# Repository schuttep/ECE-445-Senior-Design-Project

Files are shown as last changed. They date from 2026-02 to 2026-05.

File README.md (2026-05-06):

# ECE 445 Senior Design Project — Networked Physical Chessboard (Group 51)

## Project Overview

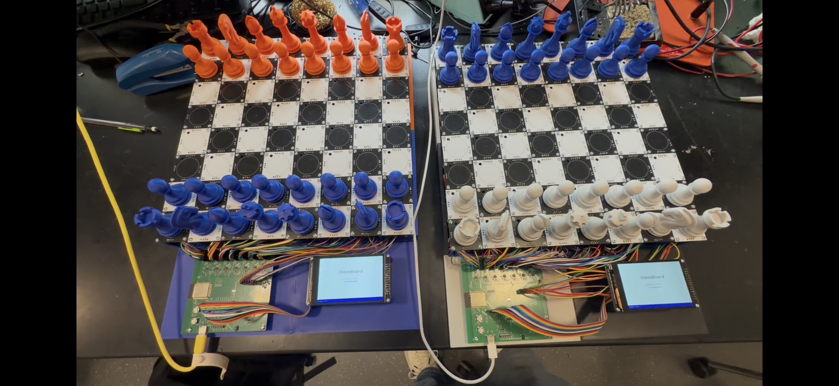
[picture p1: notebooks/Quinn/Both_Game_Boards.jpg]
Both Game Boards


This project proposes a networked physical chessboard hardware platform designed to support customizable software experiences built around real-world chess interaction. The system enables remote players to play chess using physical pieces while maintaining board synchronization through wireless communication and magnetic piece detection. This document explores the problem being solved and the approach Group 51 is taking to develop a flexible hardware foundation for future software expansion. Furthermore, the requirements and designs used to meet those requirements for each subsystem are presented. The compatibility and accuracy of the sensors and analog-to-digital converters are validated through basic calculations and engineering analysis. Finally, the ethical considerations and societal impact of the project are discussed.

---

## Table of Contents

1. [Problem Statement](#problem-statement)
2. [Proposed Solution](#proposed-solution)
3. [System Architecture](#system-architecture)
4. [Subsystem Descriptions](#subsystem-descriptions)
   - [Microcontroller & Firmware](#microcontroller--firmware)
   - [Piece Detection (Hall-Effect Sensors & ADCs)](#piece-detection-hall-effect-sensors--adcs)
   - [Display & Touchscreen UI](#display--touchscreen-ui)
   - [Wireless Communication & Backend](#wireless-communication--backend)
   - [Game Logic & FSM](#game-logic--fsm)
   - [Power & PCB Design](#power--pcb-design)
5. [Requirements & Verification](#requirements--verification)
6. [Engineering Analysis](#engineering-analysis)
7. [Ethical Considerations & Societal Impact](#ethical-considerations--societal-impact)
8. [Team Members](#team-members)
9. [Repository Structure](#repository-structure)

---

## Problem Statement

Traditional online chess is played entirely in software, disconnecting players from the tactile experience of moving physical pieces on a board. Existing products that bridge the physical and digital chess experience are either prohibitively expensive, proprietary, or locked to a single software platform. There is a need for an open, extensible hardware platform that can detect real piece positions, synchronize state between two remote boards over a network, and serve as a foundation for a rich set of software-defined game experiences.

---

## Proposed Solution

Group 51 designed and built a pair of networked physical chessboards, each built around an **ESP32-S3** microcontroller. Each board detects the position of every piece using an array of 64 Hall-effect sensors (one per square) read through eight **ADS7128** 12-bit I2C ADCs. A **480×320 IPS touchscreen** provides the primary user interface for game control, move confirmation, chat, timer display, and AI hints. The two boards communicate through an **AWS API Gateway + DynamoDB** backend, which acts as a state store to synchronize game state between remote players in real time.

| | |
|---|---|
| Assembled Board and Pieces | Full Board Assembled |

Key software features include:
- Full chess rule validation (castling, en passant, promotion, check, checkmate, stalemate) running entirely on the microcontroller.
- A finite-state machine (FSM) game controller that decouples hardware input from network and display logic.
- An on-board chat panel with a touchscreen keyboard, polled every 5 seconds.
- Optional game clocks (Rapid: 10 min/side; Bullet: 5 min/side) tracked on the Arduino.
- Stockfish AI hints (3 per game) fetched from the cloud backend.
- A WiFi network selector and password entry screen rendered at runtime.

---

## System Architecture

```
┌──────────────────────────────────────────────────────────┐
│                     ESP32-S3 (per board)                 │
│                                                          │
│  ┌────────────┐   ┌──────────────┐   ┌────────────────┐ │
│  │  ADC Layer │   │  Game Logic  │   │  Display Layer │ │
│  │ 8× ADS7128 │──▶│  (FSM + rule │──▶│ ST7365P 480×320│ │
│  │ 64 Hall Sx │   │  validation) │   │ GT911 touch    │ │
│  └────────────┘   └──────┬───────┘   └────────────────┘ │
│                          │                               │
│                   ┌──────▼───────┐                       │
│                   │  WiFi / HTTPS│                       │
│                   │  api_connect │                       │
│                   └──────┬───────┘                       │
└──────────────────────────┼───────────────────────────────┘
                           │ HTTPS / AWS API Gateway
              ┌────────────▼────────────────┐
              │  AWS Lambda + DynamoDB       │
              │  (game state, move history,  │
              │   chat, timer, AI hints)     │
              └─────────────────────────────┘
                           │
┌──────────────────────────┼───────────────────────────────┐
│                     ESP32-S3 (remote board)               │
│                        (mirror architecture)              │
└──────────────────────────────────────────────────────────┘
```

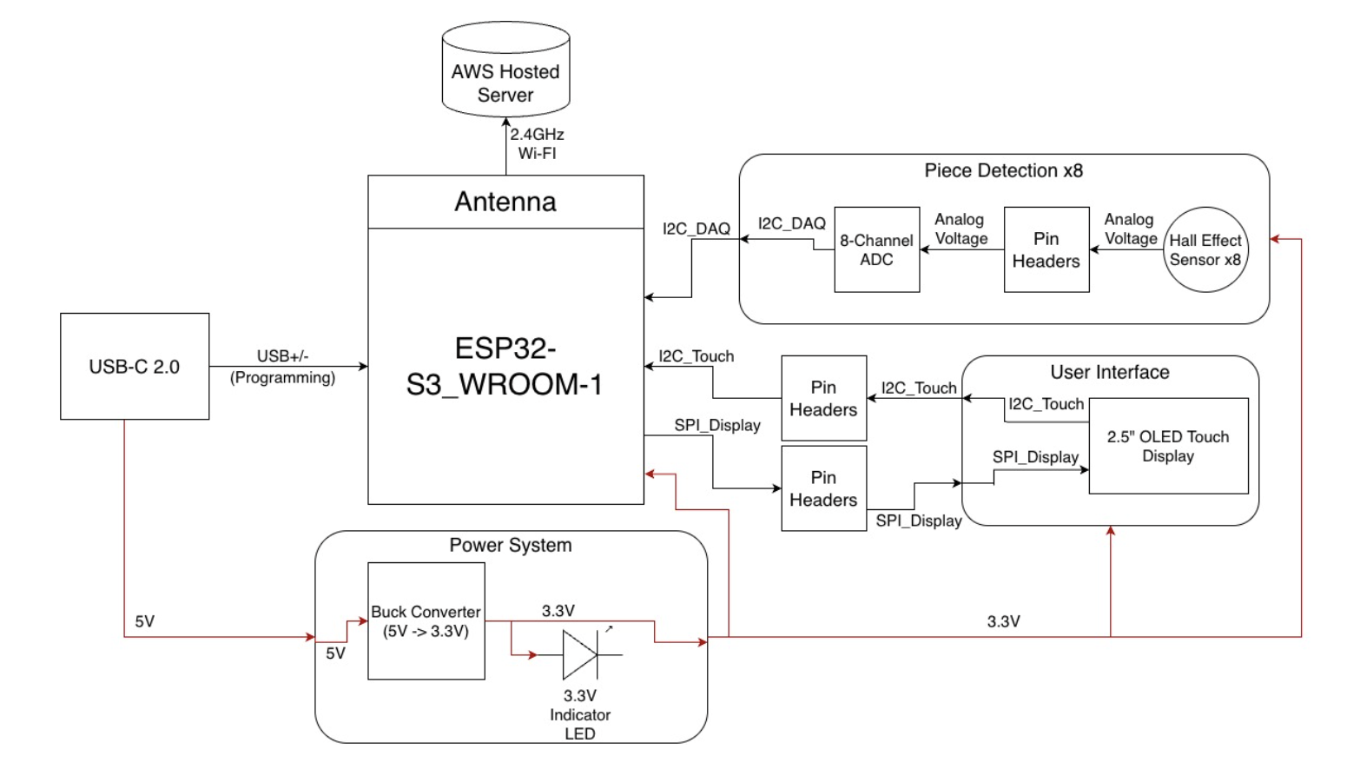
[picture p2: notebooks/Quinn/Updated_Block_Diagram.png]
System Block Diagram


---

## Subsystem Descriptions

### Microcontroller & Firmware

**Part:** Espressif ESP32-S3  
**Interfaces:** SPI (display), I2C × 2 (touch + ADCs), WiFi 802.11 b/g/n

The ESP32-S3 was selected for its dual-core Xtensa LX7 processor, ample GPIO, hardware SPI/I2C peripherals, and built-in WiFi. Two independent I2C buses are used: `Wire` for the touchscreen controller and `Wire1` (GPIO 38/39, 100 kHz) for the eight ADC chips. The main loop runs a tight read → FSM-tick → redraw cycle; only dirty screen regions are repainted each iteration to maintain UI responsiveness.

**Firmware modules:**

| File | Responsibility |
|---|---|
| `ChessBoard.ino` | Hardware init, UI state machine, touch dispatch, main loop |
| `gameloop.cpp/.h` | FSM game controller (12 states) |
| `gamelogic.cpp/.h` | Pure chess rule validation |
| `ADC_driver.cpp/.h` | ADS7128 driver, board FEN assembly |
| `display_driver.cpp/.h` | All screen rendering with dirty-cell cache |
| `api_connect.cpp/.h` | HTTPS communication with AWS backend |
| `wifi_manager.cpp/.h` | WiFi scan and credential management |

---

### Piece Detection (Hall-Effect Sensors & ADCs)

**Sensors:** 64 Hall-effect sensors, one per square (magnetic piece bases)  
**ADCs:** 8× Texas Instruments ADS7128 (12-bit, 8-channel, I2C)  
**I2C Addresses:** `0x10` – `0x17`

Each chess piece has a small permanent magnet embedded in its base. The Hall-effect sensor beneath each square measures the magnetic field strength and polarity. The ADS7128 converts the analog sensor voltage to a 12-bit digital value. The firmware interprets deviations from the 2048 mid-scale baseline:

| Condition | ADC Value | Interpretation |
|---|---|---|
| No piece | ~2048 | Empty square (`.`) |
| N-pole detected (positive deviation ≥ 300 counts) | > 2348 | White piece (`P`) |
| S-pole detected (negative deviation ≥ 300 counts) | < 1748 | Black piece (`p`) |

The physical column-to-chip mapping compensates for PCB routing constraints:

```
File a → h  maps to chips:  {7, 6, 5, 4, 0, 1, 2, 3}
```

The `localIsWhite` flag mirrors the entire board reading when the local player is Black, ensuring rank 8 always corresponds to the opponent's back rank regardless of board orientation.

**ADC Self-Test:** `testADCs()` probes all eight chips and all 64 channels at startup, reporting any unresponsive sensors.

| Game Piece with Magnet | Magnet Installation | Hall-Effect Sensor Prototype | ADC Testing Setup |
|---|---|---|---|
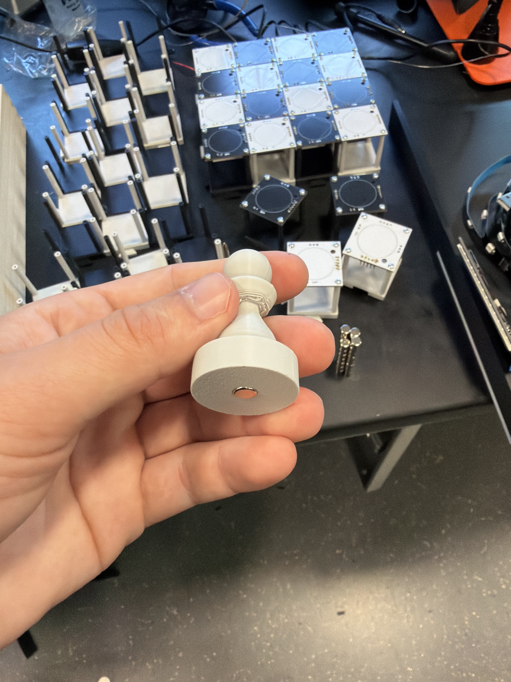
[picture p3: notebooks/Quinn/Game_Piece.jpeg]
Game Piece
|  | Magnets in Pieces | Hall Effect Sensors on Breadboard | ADC Testing Setup |

---

### Display & Touchscreen UI

**Display:** DFRobot ST7365P 480×320 IPS, Hardware SPI  
**Touchscreen:** Goodix GT911 capacitive, I2C (`Wire`, address `0x5D`)

The display operates in landscape mode (480×320). Raw portrait touch coordinates from the GT911 are transformed to landscape at runtime:

$$t_x = 479 - \text{raw}_y, \quad t_y = \text{raw}_x$$

A per-square dirty-cache system (`s_dirtyCells`, 64-bit bitfield) ensures only changed squares are redrawn each loop iteration, keeping frame latency low even on a 480×320 panel.

**UI Screens:**

| Screen State | Description |
|---|---|
| `MENU` | Main menu: Create Game, Join Game, Board Test |
| `GAME` | Live board + right panel (clocks, chat, hint button) |
| `BOARD_SYNC` | Overlay highlighting missing or extra pieces during setup |
| `WIFI_LIST` | Scanned network list with signal strength |
| `WIFI_PASS_SCREEN` | On-screen keyboard for WiFi password entry |
| `TIMER_MODE_SELECT` | Select Unlimited / Rapid / Bullet time control |
| `AI_MODE_SELECT` | Select Easy / Medium / Hard Stockfish difficulty |
| `BOARD_TEST` | Raw sensor value display for hardware validation |

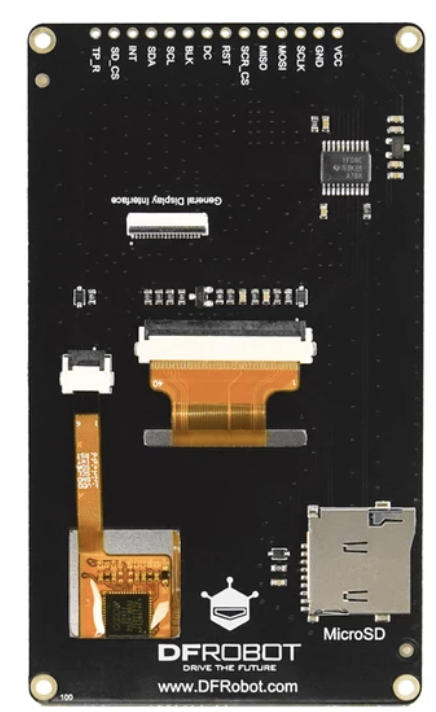
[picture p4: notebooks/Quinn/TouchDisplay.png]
Touch Display UI


---

### Wireless Communication & Backend

**Protocol:** HTTPS (TLS) over WiFi 802.11 b/g/n  
**Backend:** AWS API Gateway → AWS Lambda → DynamoDB  
**Base URL:** `https://j3zvk9adv0.execute-api.us-east-2.amazonaws.com/api/v1`

The backend is a **stateless REST API**; chess rule enforcement and move validation run entirely on the ESP32-S3. The server stores game state, move history, timer state, and chat messages. Optimistic concurrency control (`expectedVersion`) prevents conflicting simultaneous updates.

**API Endpoints:**

| Method | Endpoint | Function |
|---|---|---|
| `GET` | `/games/1` | Fetch current game state (FEN, turn, version) |
| `GET` | `/games/1/moves` | Fetch full move history |
| `POST` | `/games/1/moves` | Submit a validated move + updated FEN |
| `POST` | `/games/1/reset` | Reset game to starting position |
| `POST` | `/games/1/heartbeat` | Connectivity keepalive (every ~3 s) |
| `POST` | `/games/1/timeout` | Notify server of clock expiry |
| `GET` | `/games/1/messages` | Fetch chat messages |
| `POST` | `/games/1/messages` | Send a chat message |
| `POST` | `/games/1/hint` | Request Stockfish best-move hint |

The Amazon Root CA 1 TLS certificate is embedded directly in firmware (valid until 2038). All API calls verify WiFi connectivity before attempting a request.

---

### Game Logic & FSM

**FSM Controller (`gameloop.cpp`)** drives the full game lifecycle through 12 states:

| State | Description |
|---|---|
| `CGM_WAIT_FOR_GAME_START` | Idle on the menu |
| `CGM_JOIN_POLLING` | Polling server until opponent's first move appears |
| `CGM_GAME_INITIALIZATION` | Fetching initial game state from server |
| `CGM_BOARD_SYNC` | Waiting for physical board to match the expected position |
| `CGM_LOCAL_TURN_WAIT_FOR_BOARD` | Waiting for player to lift and place a piece |
| `CGM_LOCAL_TURN_PROMOTION` | Waiting for promotion piece selection via touchscreen |
| `CGM_LOCAL_TURN_VALIDATE` | Validating the detected move against chess rules |
| `CGM_LOCAL_TURN_CONFIRM` | Waiting for player to confirm or cancel the move |
| `CGM_SEND_STATE` | Sending confirmed move and FEN to server |
| `CGM_WAIT_FOR_REMOTE_MOVE` | Polling server for opponent's move |
| `CGM_APPLY_REMOTE_MOVE` | Waiting for player to replicate opponent's move on the board |
| `CGM_GAME_END` | Game over (checkmate, stalemate, timeout) |

**Rule Validator (`gamelogic.cpp`)** is a self-contained chess engine with no hardware or network dependencies. It validates any before/after FEN pair against the complete ruleset including castling rights, en passant captures, pawn promotion, and king safety (check, checkmate, stalemate detection).

| Working Single Board Game | Mock Demo |
|---|---|
| Working Single Board Game | Mock Demo |

---

### Power & PCB Design

The project uses two custom PCBs:

**Main Board PCB** (`ECE-445-PCBs/Main_Board/`)  
Hosts the ESP32-S3, display/touch connectors, power regulation, and I2C bus breakout for the ADC array. Gerber files are provided for fabrication.

**Tile PCB** (`ECE-445-PCBs/Tile_PCB/`)  
A small per-square PCB carrying one Hall-effect sensor. 64 tiles tile together to form the 8×8 sensing matrix. Each tile connects to the column ADC via a shared I2C bus segment.

**Main Board PCB:**

| 3D View | PCB Routing | Assembled & Soldered |
|---|---|---|
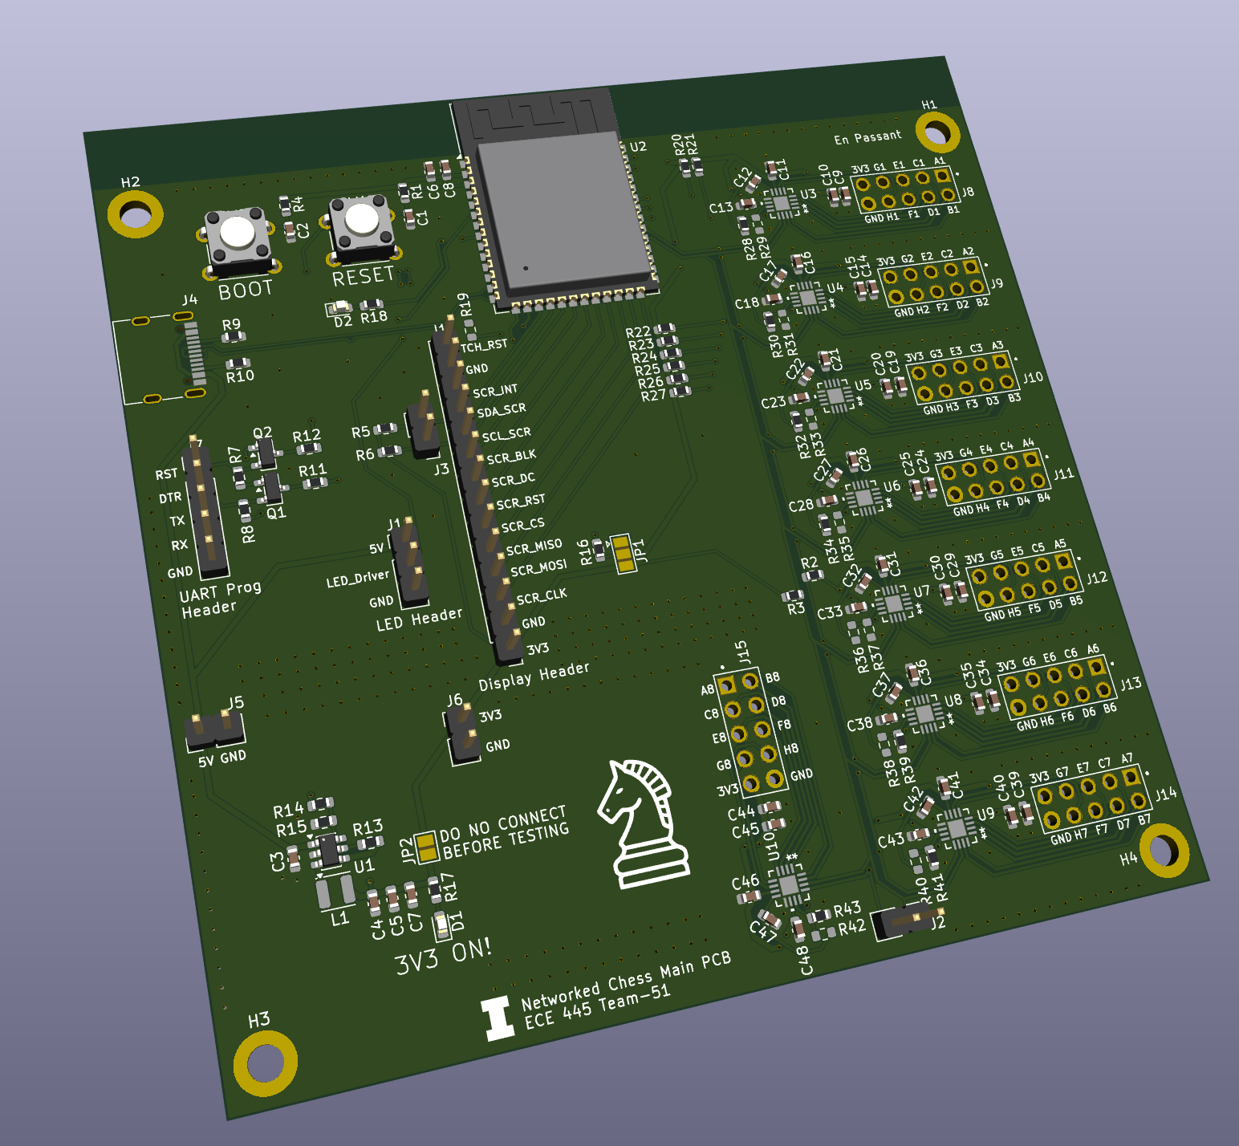
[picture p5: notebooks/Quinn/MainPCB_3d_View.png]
Main PCB 3D View
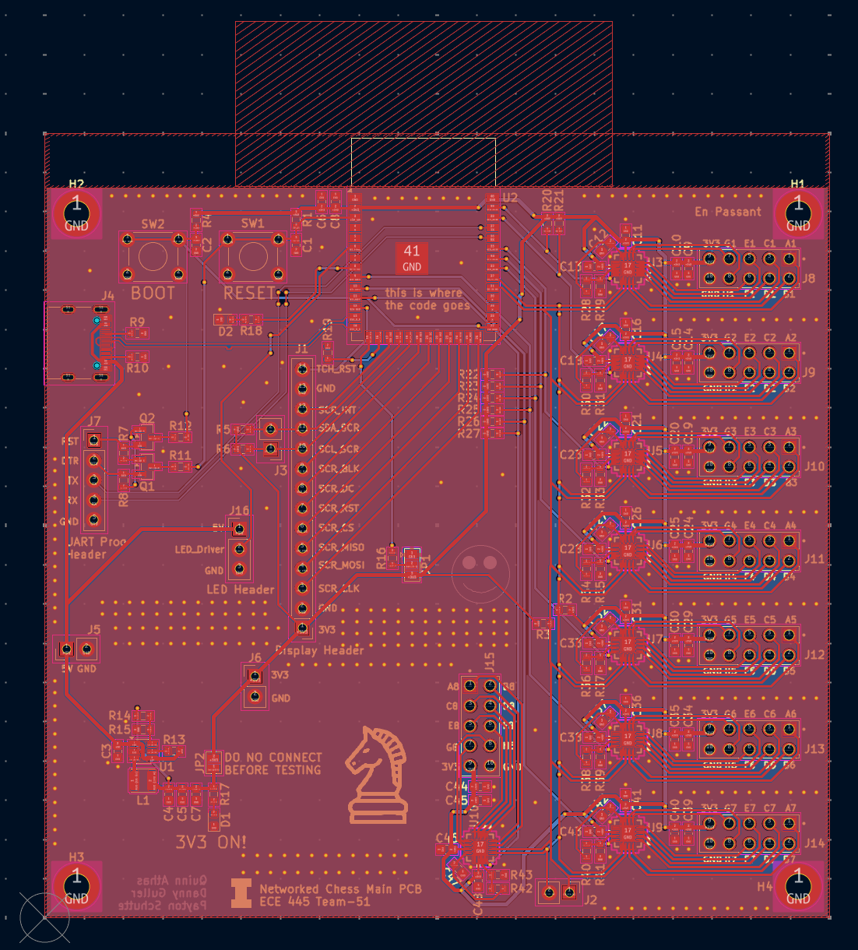
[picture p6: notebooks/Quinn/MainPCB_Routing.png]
Main PCB Routing
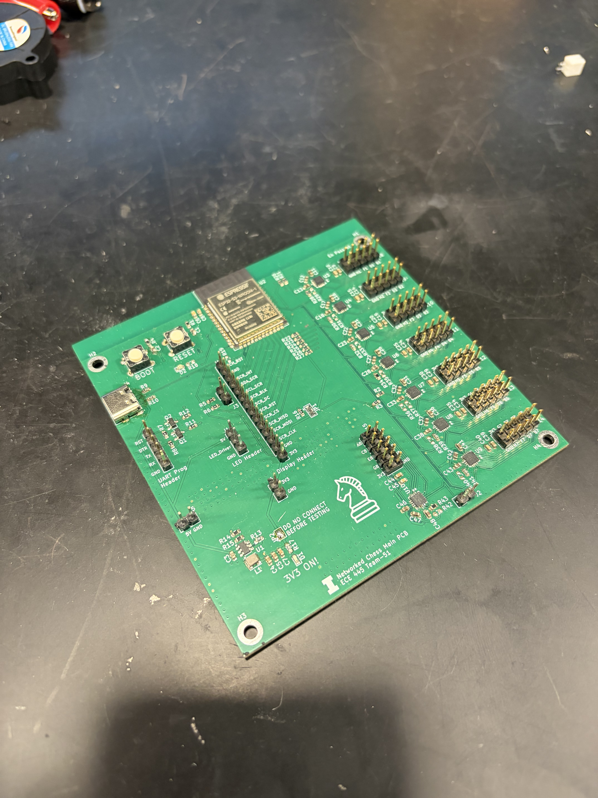
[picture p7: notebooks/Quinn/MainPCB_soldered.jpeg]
Main PCB Soldered
|  |  |  |

**Tile PCB:**

| 3D View (Front) | 3D View (Back) | PCB Routing | Soldered | Wiring |
|---|---|---|---|---|
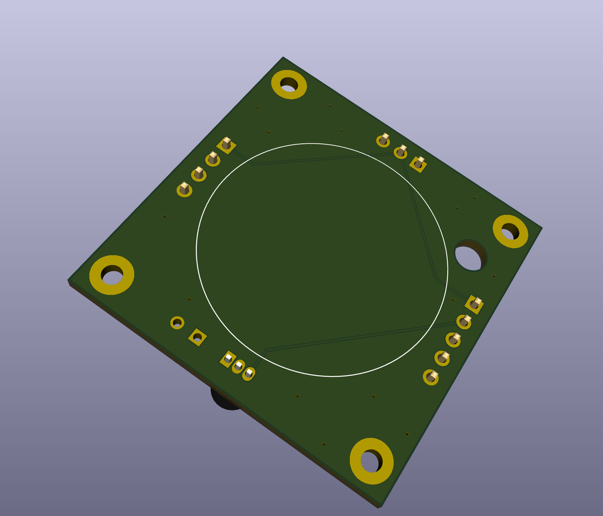
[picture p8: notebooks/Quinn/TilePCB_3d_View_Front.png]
Tile PCB 3D Front
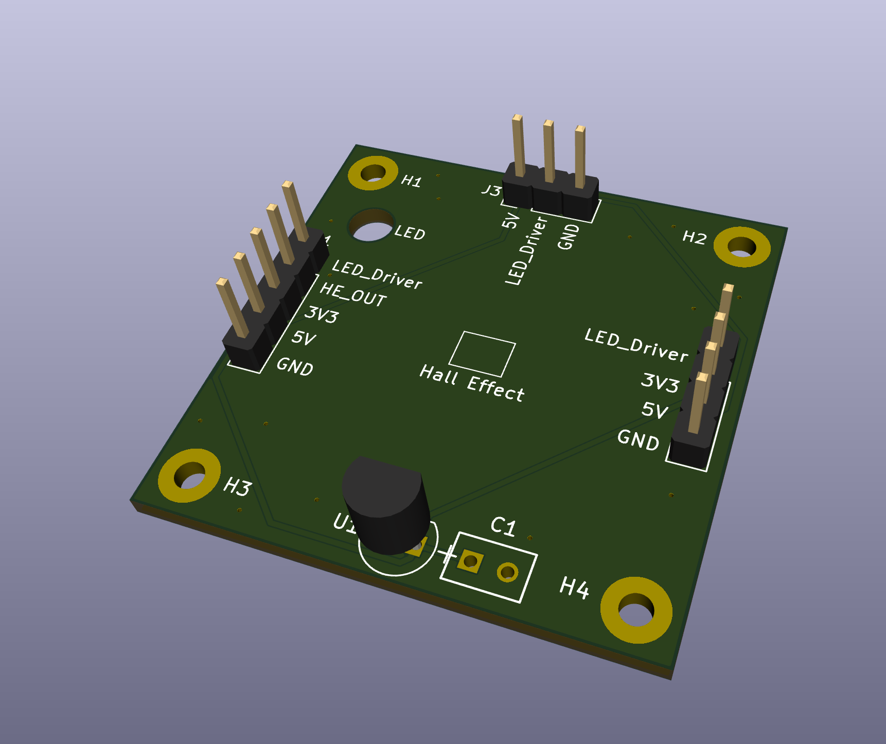
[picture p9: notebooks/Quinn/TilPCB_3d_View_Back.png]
Tile PCB 3D Back
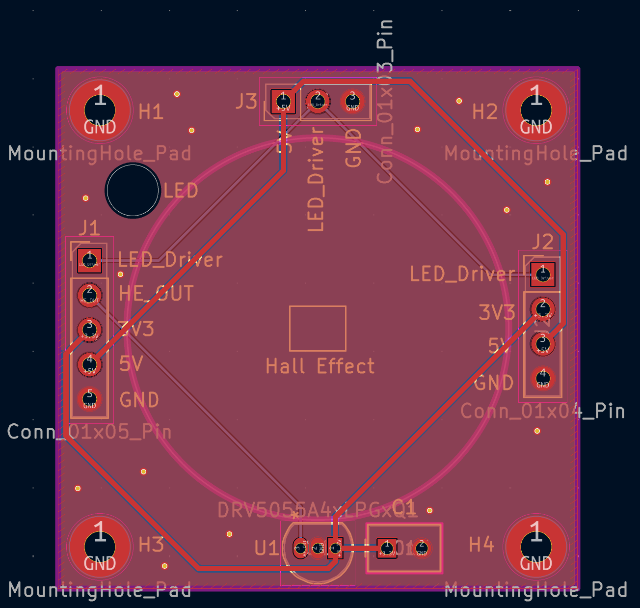
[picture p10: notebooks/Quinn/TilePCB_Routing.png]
Tile PCB Routing
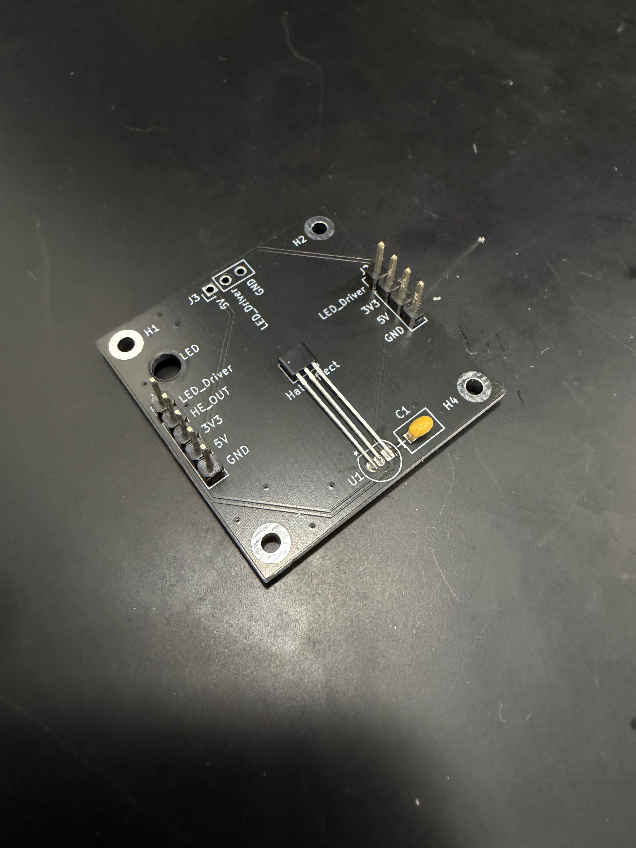
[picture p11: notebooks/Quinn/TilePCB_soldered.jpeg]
Tile PCB Soldered
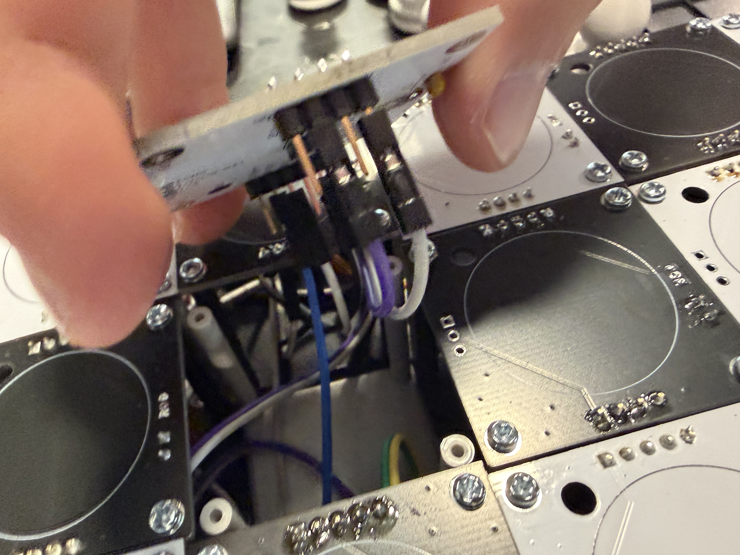
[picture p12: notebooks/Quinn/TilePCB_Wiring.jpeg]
Tile PCB Wiring
|  |  |  |  |  |

**3D-Printed Enclosure** (Fusion 360 source files and STLs in `Enclosure/`):

| Baseplate Corner | Baseplate Edge | Display Support | Tile PCB Support | Main Board Support |
|---|---|---|---|---|
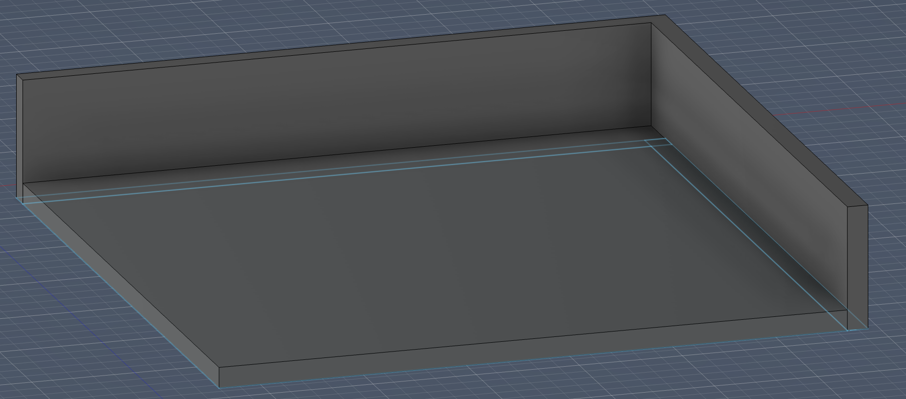
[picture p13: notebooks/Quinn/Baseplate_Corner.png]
Baseplate Corner
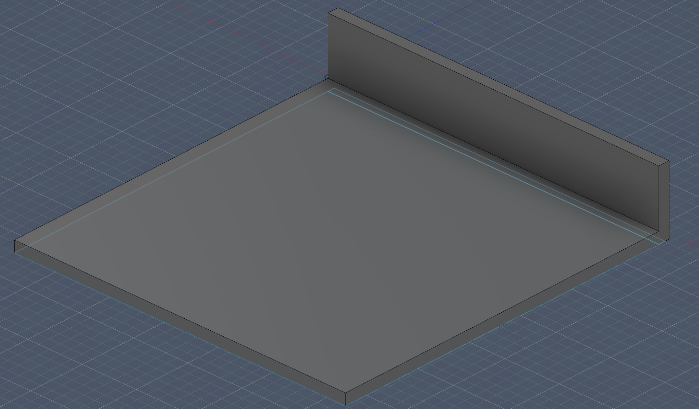
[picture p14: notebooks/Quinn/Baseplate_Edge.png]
Baseplate Edge
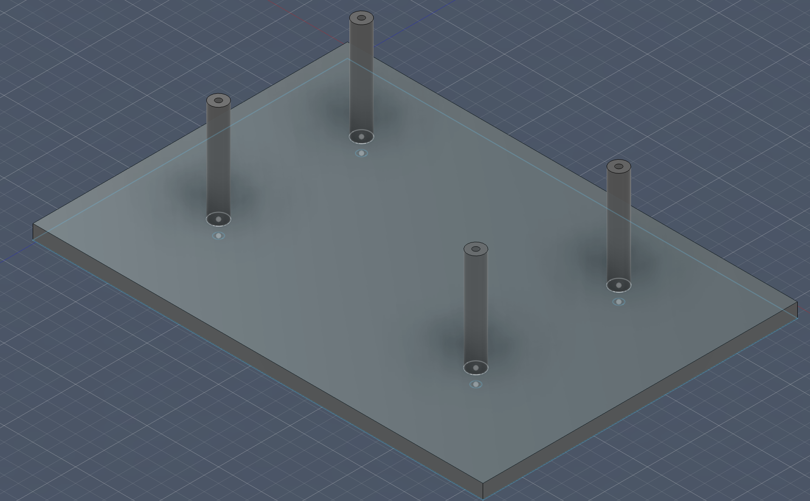
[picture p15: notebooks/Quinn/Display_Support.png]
Display Support
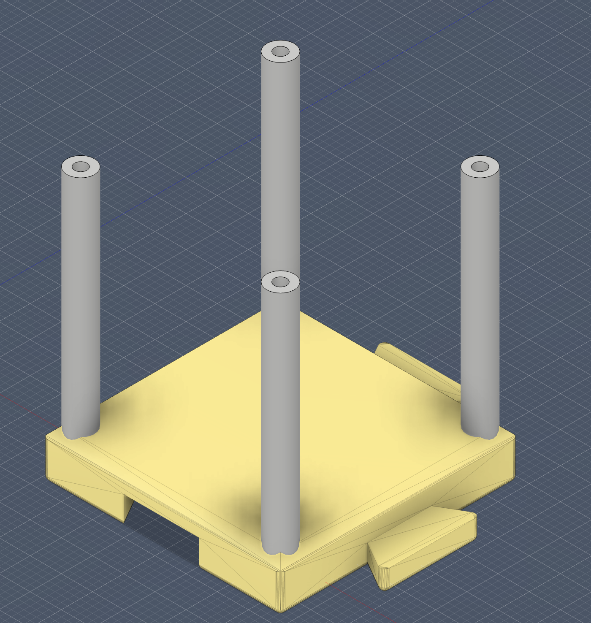
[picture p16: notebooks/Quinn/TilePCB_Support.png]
Tile PCB Support
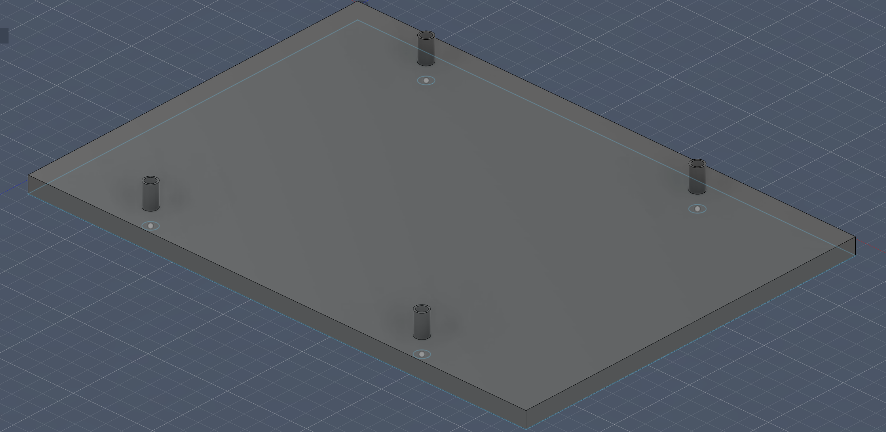
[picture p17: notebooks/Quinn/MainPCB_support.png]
Main Board Support
|  |  |  |  |  |

---

## Build Process

| Reflow Soldering Main PCB | Soldering Tile PCBs | Quarter Board Assembled | Full Board Assembled |
|---|---|---|---|
| Reflow Soldering Main PCB | Soldering Tile PCBs | Quarter of Board Assembled | Full Board Assembled |

| First Completed Board | Second Completed Board |
|---|---|
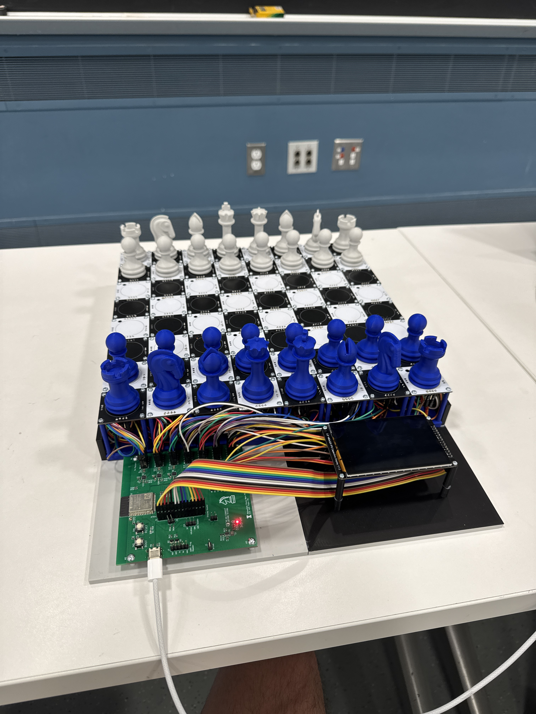
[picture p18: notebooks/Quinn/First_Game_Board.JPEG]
First Game Board
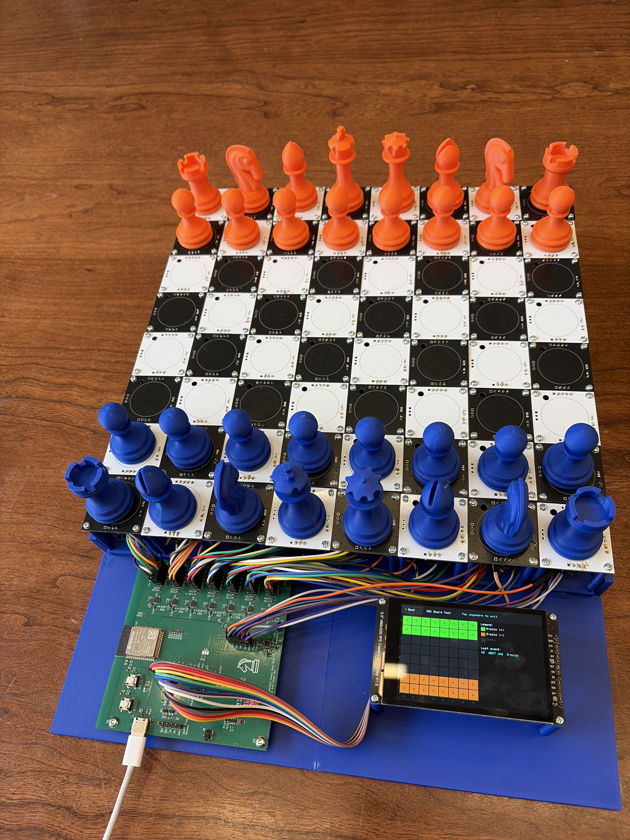
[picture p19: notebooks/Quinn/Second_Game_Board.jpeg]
Second Game Board
|  |  |

---

## Requirements & Verification

| Requirement | Verification Method |
|---|---|
| All 64 squares reliably detect piece presence/absence | ADC self-test (`testADCs()`); manual placement of pieces across all squares |
| Board FEN matches physical position within 1 loop cycle (~50 ms) | Serial monitor comparison of sensor FEN vs. expected FEN during test positions |
| WiFi connection established within 10 seconds of credential entry | Timed connection attempts in `wifi_manager.cpp` |
| Move validated and sent to server within 3 seconds of confirmation | Timestamped serial log during live game |
| Remote move received and displayed within 5 seconds of opponent submission | End-to-end latency test between two boards |
| Chat messages delivered within 10 seconds | Measured poll cycle (`MSG_POLL_INTERVAL_MS = 5000 ms`) |
| Timer accuracy within ±1 second per 10 minutes of play | Comparison of Arduino millis() clock against reference timer |
| Touchscreen registers all button presses with < 100 ms response | Manual interaction testing across all UI screens |

---

## Engineering Analysis

### Hall-Effect Sensor Threshold Calculation

The ADS7128 is a 12-bit ADC with a 3.3 V reference, giving a resolution of:

$$\Delta V = \frac{3.3\text{ V}}{2^{12}} \approx 0.806 \text{ mV/count}$$

The firmware uses a ±300 count threshold around the 2048 midpoint:

$$\Delta V_{\text{threshold}} = 300 \times 0.806 \text{ mV} \approx 242 \text{ mV}$$

This threshold was chosen to be large enough to reject sensor noise (empirically measured at < 20 counts RMS) while reliably detecting the magnetic field of the embedded piece magnets (measured at 400–800 counts deviation at rated piece height).

### I2C Bus Timing

Eight ADS7128 chips share the `Wire1` bus at 100 kHz. A full board scan reads 64 channels sequentially. Each channel read requires approximately 3 I2C transactions (register select + 2-byte read), each taking:

$$t_{\text{transaction}} \approx \frac{3 \times 18 \text{ bits}}{100{,}000 \text{ bps}} \approx 540 \text{ µs}$$

Total scan time estimate:

$$t_{\text{scan}} \approx 64 \times 540 \text{ µs} \approx 34.6 \text{ ms}$$

This is well within the target loop period of ~50 ms, leaving sufficient headroom for display updates, FSM logic, and WiFi polling.

### Optimistic Concurrency

The server uses a version counter to prevent conflicting move submissions. If both boards somehow attempt to push a move simultaneously, the server rejects the request with a lower `expectedVersion`, and the losing board re-fetches the current state before retrying. This eliminates the need for server-side locking in a two-player scenario.

---

## Ethical Considerations & Societal Impact

**Accessibility:** The physical-digital bridge this project creates enables players who prefer or require tactile interaction — including visually impaired users with adapted piece markings — to participate in networked chess. The touchscreen UI is designed with large tap targets and high-contrast color themes.

**Privacy & Data:** The system transmits only game state (FEN strings), optional chat messages, and anonymous heartbeat signals. No personally identifiable information is collected or stored by the backend. Credentials (WiFi SSID/password) are stored locally in `secrets.h` and are never transmitted to the cloud.

**Security:** All client–server communication is over TLS (HTTPS) with a pinned Amazon Root CA certificate. The backend uses optimistic concurrency control to prevent unauthorized state manipulation. WiFi credentials are excluded from version control via `.gitignore`.

**Open Hardware Philosophy:** All PCB design files (KiCad), 3D enclosure models (Fusion 360), and firmware are maintained in this repository, enabling the community to reproduce, modify, and extend the platform without proprietary lock-in.

**Societal Impact:** Chess is a globally played game with deep cultural significance. By lowering the cost and technical barrier to networked physical chess, this platform has the potential to reconnect distributed families and communities through shared physical play experiences, and to serve as an educational platform for embedded systems and game AI coursework.

---

*ECE 445 — Senior Design Laboratory, University of Illinois Urbana-Champaign*  
*Group 51 — Spring 2026*

---

## Repository Structure

```
ChessBoard/          ← Production firmware (ESP32-S3 Arduino sketch)
ECE-445-PCBs/        ← KiCad PCB design files + Gerbers
Enclosure/           ← Fusion 360 source files + STLs
prototypes/          ← Early-stage / exploratory sketches (non-production)
backend/
  api.py               ← AWS Lambda handler (backend)
  api.md               ← Full REST API endpoint reference
docs/
  diagrams/
    ChessBoard.drawio  ← System block diagram (editable)
Danny/               ← Build photos and design notes
Quinn/               ← Build photos, PCB renders, enclosure renders
Payton/              ← Design notes
README.md            ← This file
```

**Prototype sketches** (`prototypes/`) are independent `.ino` files used during development to validate individual subsystems (ADC driver, display, hall sensor, WiFi). They are not part of the production build in `ChessBoard/`.

**API documentation** is maintained in [`backend/api.md`](backend/api.md). The backend source is [`backend/api.py`](backend/api.py) (AWS Lambda + DynamoDB).

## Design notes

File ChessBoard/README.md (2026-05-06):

# ChessBoard — ECE 445 Senior Design Project

A networked, physical chess board built on the ESP32-S3. Two boards communicate through an AWS backend, allowing two players to play chess on real hardware with piece detection, touchscreen UI, a live chat panel, optional chess clocks, and Stockfish AI hints.

---

## Table of Contents

1. [Hardware Overview](#hardware-overview)
2. [Pin Assignments](#pin-assignments)
3. [Dependencies / Libraries](#dependencies--libraries)
4. [Project Setup](#project-setup)
5. [File Reference](#file-reference)
6. [Backend API](#backend-api)
7. [Game Flow](#game-flow)
8. [Testing Utilities](#testing-utilities)

---

## Hardware Overview

| Component | Part | Interface |
|---|---|---|
| Microcontroller | ESP32-S3 | — |
| Display | DFRobot ST7365P 480×320 IPS | Hardware SPI |
| Touchscreen | GT911 capacitive | I2C (`Wire`, 0x5D) |
| Hall-effect ADCs | 8× ADS7128 (addresses 0x10–0x17) | I2C (`Wire1`, 100 kHz) |
| Hall sensors | 64× (one per square) | Analog via ADS7128 |

Each ADS7128 chip handles one column of the board (8 squares = 8 channels). Chips are physically wired out of order; the mapping is handled in firmware — see `ADC_driver.cpp`.

The display is in **landscape** mode (480×320). The touchscreen reports raw portrait coordinates which are converted to landscape in `ChessBoard.ino`:
```
tx = 479 - raw_y
ty = raw_x
```

---

## Pin Assignments

Defined in `headers.h`:

| Pin | GPIO | Function |
|---|---|---|
| `SDA_DAQ` | 38 | ADC I2C data (Wire1) |
| `SCL_DAQ` | 39 | ADC I2C clock (Wire1) |
| `SCR_SCLK` | 45 | Display SPI clock |
| `SCR_MOSI` | 48 | Display SPI data |
| `SCR_MISO` | 47 | Display SPI (unused) |
| `SCR_CS` | 21 | Display chip select |
| `SCR_RST` | 14 | Display reset |
| `SCR_DC` | 13 | Display data/command |
| `SCR_BLK` | 12 | Display backlight |
| `SCR_I2C_SCL` | 11 | Touch I2C clock (Wire) |
| `SCR_I2C_SDA` | 10 | Touch I2C data (Wire) |
| `SCR_INT` | 9 | Touch interrupt |
| `SCR_TCH_RST` | 8 | Touch reset |

---

## Dependencies / Libraries

Install all libraries through the Arduino IDE Library Manager or manually place them in your Arduino `libraries/` folder.

| Library | Purpose |
|---|---|
| `DFRobot_GDL` | ST7365P display driver |
| `DFRobot_Touch` | GT911 touchscreen driver |
| `WiFi` | Built-in ESP32 WiFi |
| `WiFiClientSecure` | TLS/HTTPS connections |
| `HTTPClient` | HTTP requests to AWS |
| `ArduinoJson` | JSON parsing/serialization |
| `Wire` | I2C (built-in) |
| `SPI` | SPI (built-in) |

**Board**: Install **esp32 by Espressif Systems** via the Arduino Boards Manager. Select **ESP32S3 Dev Module** as the target board.

---

## Project Setup

### 1. Clone / copy the sketch

The Arduino IDE requires the sketch folder name to match the `.ino` filename. The folder must be named `ChessBoard` and contain `ChessBoard.ino`.

### 2. Create `secrets.h`

Create `ChessBoard/secrets.h` (not committed to version control):

```cpp
#pragma once
#define WIFI_SSID "YourNetworkName"
#define WIFI_PASS "YourPassword"
```

At startup the board will attempt to connect to these credentials automatically. If the connection fails, the on-screen WiFi selector lets you choose a different network.

### 3. Install libraries

See [Dependencies](#dependencies--libraries) above.

### 4. Select board and port

In the Arduino IDE:
- **Tools → Board → ESP32S3 Dev Module**
- **Tools → Port** → select the correct COM port for your ESP32-S3

### 5. Upload

Press **Upload**. Open **Serial Monitor** at 115200 baud to see FSM state logs.

---

## File Reference

### `ChessBoard.ino`
**Main sketch — hardware init, UI, touch handling, and main loop.**

- Initialises the display, ADCs, game FSM, and WiFi on boot.
- Manages a `ScreenState` enum (`MENU`, `GAME`, `BOARD_TEST`, `EDGE_CASE_TEST`, `WIFI_LIST`, `WIFI_PASS_SCREEN`, `TIMER_MODE_SELECT`, `AI_MODE_SELECT`).
- `setup()` — initialises hardware, connects to WiFi, shows the menu.
- `loop()` — reads the physical board every iteration, feeds it to the FSM via `cgm_setPhysicalBoardFEN()`, calls `cgm_tick()`, then redraws only the parts of the screen that have changed (dirty tracking via `gs_*` static variables).
- Handles all touch events: menu navigation, move confirm/cancel, promotion selection, WiFi picker, chat composer, hint button.
- Chat messages are polled every 5 seconds (`MSG_POLL_INTERVAL_MS`).
- Each game grants 3 Stockfish hints (`gs_hintsLeft`).

---

### `gameloop.cpp` / `gameloop.h`
**Finite state machine (FSM) that drives the game.**

This is the core game controller. It is entirely decoupled from hardware; it receives the physical board state as a string and calls display/network functions only through well-defined helpers.

**FSM states:**

| State | Description |
|---|---|
| `CGM_WAIT_FOR_GAME_START` | Idle on the menu |
| `CGM_JOIN_POLLING` | Polling server until white's first move appears |
| `CGM_GAME_INITIALIZATION` | Fetching initial game state from server |
| `CGM_BOARD_SYNC` | Waiting for physical board to match the expected position |
| `CGM_LOCAL_TURN_WAIT_FOR_BOARD` | Waiting for player to make a physical move |
| `CGM_LOCAL_TURN_PROMOTION` | Waiting for player to choose a promotion piece |
| `CGM_LOCAL_TURN_VALIDATE` | Validating the detected move against chess rules |
| `CGM_LOCAL_TURN_CONFIRM` | Waiting for player to confirm or cancel on touchscreen |
| `CGM_SEND_STATE` | Sending the confirmed move to the server |
| `CGM_WAIT_FOR_REMOTE_MOVE` | Polling server for opponent's move |
| `CGM_APPLY_REMOTE_MOVE` | Waiting for player to replicate opponent's move on board |
| `CGM_GAME_END` | Game over (checkmate, stalemate, timeout) |
| `CGM_ERROR_STATE` | Unrecoverable FSM error |

**Key public API:**

```cpp
void cgm_setup();                            // call once in setup()
void cgm_tick();                             // call every loop()
void cgm_setPhysicalBoardFEN(const String&); // feed sensor reading each loop

void cgm_createGameNow(bool aiMode);         // create game as white
void cgm_joinGameNow();                      // join game as black
void cgm_confirmPendingMove();               // touch: confirm button
void cgm_cancelPendingMove();                // touch: cancel button
void cgm_selectPromotionPiece(char piece);   // touch: promotion picker
void cgm_requestNewGame();                   // touch: play again
void cgm_loadEdgeCaseFEN(...);               // load a test position
void cgm_setTimerMode(TimerMode);            // set before createGame
void cgm_setAiDifficulty(AiDifficulty);      // set before createGame (AI only)
```

**Timer modes** (`TimerMode` enum): `TIMER_NONE` (unlimited), `TIMER_RAPID` (10 min), `TIMER_BULLET` (5 min). Clocks are tracked entirely on the Arduino; the server only stores the mode and initial budget.

**AI difficulty** (`AiDifficulty` enum): `AI_EASY` (depth 2), `AI_MEDIUM` (depth 5), `AI_HARD` (depth 12).

---

### `gamelogic.cpp` / `gamelogic.h`
**Pure chess move validation — no hardware or network dependencies.**

Validates any move against the full set of chess rules including castling, en passant, promotion, check, checkmate, and stalemate. Takes before/after board FEN strings and returns the validated result FEN or `"Invalid Move"`.

**Key functions:**

```cpp
String validateMoveAndReturnFEN(beforeFEN, afterFEN, whiteToMove, castling, promotionPiece, enPassantSquare);
bool hasAnyLegalMove(board, whiteToMove, castling, enPassantSquare);
bool isKingInCheck(board, whiteKing);
bool isSquareAttacked(board, row, col, byWhite);
bool parseFENBoard(fen, board[8][8]);
bool boardHasExactlyOneKingEach(board[8][8]);
```

Board encoding: uppercase = white pieces (`RNBQKP`), lowercase = black (`rnbqkp`), `.` = empty square.

---

### `ADC_driver.cpp` / `ADC_driver.h`
**ADS7128 I2C ADC driver — reads all 64 Hall effect sensors.**

Eight ADS7128 chips at I2C addresses `0x10`–`0x17` on the `Wire1` bus (GPIO 38/39, 100 kHz). Each chip reads one column of 8 squares.

Physical column-to-chip wiring (file a→h maps to chips): `{7, 6, 5, 4, 0, 1, 2, 3}`.

Piece detection threshold: ±300 counts from a 2048 baseline (12-bit ADC midpoint). N-pole deviation (positive) is encoded as `P` (white); S-pole deviation (negative) as `p` (black); no deviation as `.`.

**Public API:**

```cpp
void initADCs();                                  // Wire1.begin + configure all chips
void readBoardFEN(char* fenOut, bool localIsWhite); // fill 72-byte FEN buffer
ADCTestResult testADCs();                          // full self-test (chip + channel probe)
uint16_t readRawChannel(uint8_t chip, uint8_t ch); // single channel read (debugging)
extern const uint8_t ADC_COL_TO_CHIP[8];          // column-to-chip mapping table
```

The `localIsWhite` flag mirrors the board reading when false, so that the row of sensors nearest the black player maps to rank 8.

---

### `display_driver.cpp` / `display_driver.h`
**All screen rendering — board grid, pieces, panels, keyboard, chat.**

Uses a per-square dirty cache (`s_cachedBoard[8][8]` + 64-bit `s_dirtyCells` bitfield) so only changed squares are redrawn each loop. A separate chrome cache (`s_chromeValid`) avoids re-painting static UI chrome.

**Key functions:**

```cpp
void initDisplay();                  // call once in setup()
void drawGameScreen(...);            // full game screen with board + right panel
void drawGameScreenWithMove(...);    // game screen with before/after move highlights
void drawBoardSyncOverlay(...);      // highlights missing/extra pieces during sync
void drawPromotionPicker(bool);      // promotion piece selection overlay
void drawTimerDisplay(...);          // live clock display in right panel
void drawGameMessagePanel(...);      // live chat panel (last 3 messages)
void drawGameMessageComposer(...);   // full-screen message composer + keyboard
void drawCheckAlert(bool);           // "in check!" banner overlay
void drawGameOverScreen(const char*); // checkmate / stalemate / timeout end screen
void drawWifiListScreen(...);        // WiFi network list
void drawPasswordScreen(...);        // WiFi password entry with on-screen keyboard
void invalidateBoardCache();         // force full board repaint on next draw
```

Primitives available for composing custom screens:
```cpp
void displayClear();
void displayHeader(bool wifiConnected, bool showBack);
void displayCenteredText(text, y, size, color);
void displayButton(x, y, w, h, color, label);
void displayStatusBar(msg, bgColor);
void displayDivider(y, color);
```

---

### `api_connect.cpp` / `api_connect.h`
**All HTTPS communication with the AWS API Gateway backend.**

The certificate for Amazon Root CA 1 (valid until 2038) is embedded directly in `api_connect.cpp`. All functions check WiFi connectivity before attempting a request and return an `ok` flag.

**Endpoints and functions:**

```cpp
GameStateResult fetchGameState();                        // GET  /games/1
ApiResult pushFENState(fen, move, expectedVersion);      // POST /games/1/moves
ApiResult resetGame(timerMode, boardId, gameMode, depth);// POST /games/1/reset
ApiResult sendHeartbeat();                               // POST /games/1/heartbeat
ApiResult notifyTimeout(loserColor);                     // POST /games/1/timeout
ApiResult sendMessage(text);                             // POST /games/1/messages
FetchMessagesResult fetchMessages();                     // GET  /games/1/messages
HintResult fetchBestMove(currentFen);                   // POST /games/1/hint
```

`pushFENState` uses optimistic concurrency: it sends the current `serverVersion` and the server rejects the update if the version has changed (i.e. the opponent moved first).

---

### `wifi_manager.cpp` / `wifi_manager.h`
**WiFi scan and connect utilities.**

```cpp
uint8_t wmScan(ScannedNetwork* out);         // scan up to WM_MAX_SCAN=10 networks
bool wmConnect(const char* ssid, const char* pass); // connect, retries 40×500ms
```

`ScannedNetwork` holds `ssid[33]` and `rssi`. Used by both the auto-connect at boot and the on-screen WiFi picker.

---

### `headers.h`
**Shared pin definitions and RGB565 colour constants.**

Included by all files that need pin numbers or draw to the screen. Includes `secrets.h` so WiFi credentials are available project-wide without extra includes.

All colour constants are individually guarded with `#ifndef` so they do not conflict with definitions in the DFRobot GDL library.

---

### `secrets.h`
**WiFi credentials — not committed to version control.**

```cpp
#pragma once
#define WIFI_SSID "YourNetworkName"
#define WIFI_PASS "YourPassword"
```

This file must be created manually before building. See [Project Setup](#project-setup).

---

## Backend API

Base URL: `https://j3zvk9adv0.execute-api.us-east-2.amazonaws.com/api/v1/games/1`

Full endpoint reference: [`backend/api.md`](../backend/api.md)

The Python backend (`backend/api.py`, located in the parent `ECE-445-Senior-Design-Project/` folder) defines the Lambda handler and DynamoDB schema. Game state is a single record keyed by game ID. Boards identify themselves by MAC address; the server assigns white to the first board that calls `/reset` and black to the second board that registers.

The server does **not** run chess clocks — it only stores the timer mode and initial budget. Both boards track remaining time independently and call `/timeout` when their own clock expires.

---

## Game Flow

```
Power on
  └─ setup(): init display → init ADCs → connect WiFi → show Menu

Menu screen
  ├─ "Join Game"        → poll server until game exists → GAME screen (black)
  ├─ "Create Game"      → choose timer mode → reset server → GAME screen (white)
  ├─ "vs Stockfish AI"  → choose difficulty + timer → reset server → GAME screen (white)
  └─ "ADC Board Test"   → live sensor visualisation screen

GAME screen (FSM ticks every loop)
  ├─ Board sync: physical board must match expected position before play begins
  ├─ Local turn:
  │    detect piece lift → detect piece placed → validate move
  │    → show Confirm / Cancel buttons → player confirms → send to server
  ├─ Remote turn:
  │    poll server → receive opponent FEN → player replicates physically
  └─ Game over: checkmate / stalemate / timeout → result overlay → "Play Again"
```

---

## Testing Utilities

### ADC Board Test (`BOARD_TEST` screen)
Accessible from the main menu. Displays a live 8×8 grid showing the Hall-effect sensor differential for every square in real time. Green = N-pole detected, orange = S-pole detected, grey = empty. Useful for verifying sensor wiring and placement.

### Edge Case Test (`EDGE_CASE_TEST` screen)
Loads pre-defined FEN positions to test special chess rules without playing a full game. Available scenarios:
- Castling (kingside / queenside)
- En passant (white and black)
- Pawn promotion (white and black)

### `testADCs()` (ADC_driver)
Returns an `ADCTestResult` struct with a bitmask of which chips responded on I2C, which chips returned valid data on all 8 channels, and a total valid-channel count. Called from `runBoardTests()` in `ChessBoard.ino`.

### `readRawChannel(chip, ch)` (ADC_driver)
Returns the raw 12-bit ADC value for a single square. Useful when debugging a specific sensor.

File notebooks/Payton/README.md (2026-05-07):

# Engineering Notebook — Payton Schutte
**ECE 445 Senior Design Laboratory**
**University of Illinois Urbana-Champaign — Spring 2026**
**Project:** Networked Physical Chess Board for Remote Play (Group 51)

## Entry 1 — 2026-01-21: First Group Meeting

**Objectives:** Meet with group members for the first time, brainstorm viable project ideas, and submit candidate proposals to the course web board.

**Record:**

Met with Quinn and Danny to brainstorm project ideas. Each member proposed one concept:

| Member | Proposal |
|---|---|
| Payton | Two physical chess boards that play each other over the internet |
| Quinn | Universal game board using an E-ink display |
| Danny | Auto-dealer poker machine |

The chess board idea was chosen as the group's preferred direction. The core appeal was that it was a real physical artifact two players would interact with simultaneously, not merely a software interface on a screen. Building a physical sensing layer to detect piece positions, synchronizing state over a network, and rendering the opponent's moves locally were identified as the three main technical challenges.

All three ideas were posted to the course web board to obtain feedback from course staff before committing to a final direction.

**Design Decision:** Prioritize physical interactivity over purely digital game experience. The value proposition of the project depends on players using real pieces on a real board, so the sensing layer and physical form factor are non-negotiable constraints.

---

## Entry 2 — 2026-01-24: Getting Ideas on Paper

**Objectives:** Lock in the project direction and document the agreed feature set in writing.

**Record:**

Officially selected the Networked Physical Chess Board for Remote Play as the group project. Agreed on the core feature set:

- Two boards connected over WiFi, communicating through a shared cloud backend
- LED indicators on each board to show the opponent's most recent move
- Touch display for game UI (menus, move confirmation, status)

These decisions were written into an informal design document. Writing forced clarity about where the primary complexity would lie. Two areas stood out: (1) the sensing layer — how to reliably distinguish piece presence and absence on all 64 squares — and (2) network synchronization — how to ensure both boards always agree on the canonical game state without requiring a dedicated referee process.

**References:** None for this session; ideas based on prior knowledge of ESP32 capabilities and chess board geometry.

---

## Entry 3 — 2026-01-28: Request for Approval (RFA)

**Objectives:** Write and submit the RFA document early for extra credit. Formalize subsystems, success criteria, and initial component selections.

**Record:**

Worked with the team to write the RFA. The document covered:

- **Problem statement:** Remote chess requires players to use software clients; there is no affordable product that lets remote players use physical pieces
- **Proposed solution:** Two ESP32-based boards with Hall effect piece detection, networked via AWS
- **Subsystems identified:**
  1. Piece sensing (Hall effect sensors + ADC)
  2. Main MCU and firmware (ESP32)
  3. Display and UI (touchscreen)
  4. Network communication (WiFi + REST API)
  5. Game logic (rule validation, state machine)
- **Initial component selections:** ESP32 for WiFi integration, Hall effect sensors for non-contact piece detection, I2C ADC for multiplexing 64 sensors, DFRobot touch display for UI

**Design Decision:** Use an I2C ADC rather than direct GPIO reads from Hall sensors. The ESP32 does not have 64 available analog input pins, so multiplexing through I2C ADCs is the only practical approach. This decision drove the rest of the sensing architecture.

---

## Entry 4 — 2026-02-02: Buying Breadboard Parts

**Objectives:** Finalize and place the initial component order for breadboard prototyping.

**Record:**

Finalized the component order. Key change from the RFA: the TLA2528 ADC originally selected was out of stock on DigiKey. Substituted the **ADS7128** [R1], a 12-bit 8-channel I2C ADC with similar performance but lower cost and no unused advanced features.

Additional items ordered:
- QFN-16 breakout board (required to use the ADS7128 package on a breadboard)
- Permanent magnets for piece bases (to test Hall effect sensitivity at different distances)

**Design Decision:** Switched from TLA2528 to ADS7128. Both are 12-bit 8-channel I2C ADCs. The ADS7128 was available, cheaper, and had an existing Arduino community footprint. The key required feature — addressable I2C addressing so multiple chips can share one bus — is present on both.

Without real hardware measurements of magnetic field strength at operating distances, the viability of the entire sensing approach remained an open question at this point.

---

## Entry 5 — 2026-02-10: Preparing for First TA Meeting

**Objectives:** Prepare a block diagram that clearly shows subsystem data flow for the first TA meeting.

**Record:**

Worked with the team to build a block diagram (Fig. 1) before the TA meeting. The diagram broke the system into six subsystems and showed the data paths between them:

```
Hall Sensors (64x) --> ADS7128 ADCs (8x) --> ESP32-S3
                                                |
                                   .------------+------------.
                             Display UI        WiFi      Game Logic
                                                |
                                           AWS API
```

**Fig. 1** — High-level data flow block diagram (preliminary). Sensing data flows left to right; network data flows vertically through the MCU.

Key insight from building this diagram: the game logic layer must be coupled to both the sensing layer (to interpret physical moves) and the network layer (to push and pull state), but it should not contain any hardware-specific code itself. This separation became a guiding principle for the firmware architecture.

---

## Entry 6 — 2026-02-11: First TA Meeting

**Objectives:** Present the current design to the TA and collect feedback.

**Record:**

Presented the block diagram and described the planned approach. TA feedback:

- General direction was sound
- Some confusion about how the physical layout of two boards related to the network topology — clarified with a walkthrough of the data flow
- **Identified risk:** Hall effect sensitivity at the target operating distance (magnet embedded in piece base, sensor recessed below playing surface). Flagged as the highest-risk item requiring early validation

**Action item:** Validate Hall effect sensing performance on the breadboard as early as possible before committing to PCB layout.

---

## Entry 7 — 2026-02-13: Project Proposal Document

**Objectives:** Complete the Project Proposal Document with full subsystem specifications, component datasheets, and a schedule.

**Record:**

Finalized the Project Proposal Document. This was significantly more detailed than the RFA and required research into component datasheets:

- **ADS7128 I2C addressing:** Seven address bits configured via the ADDR pin, giving addresses `0x10`–`0x17` for the eight chips needed. This confirmed that all eight chips can share a single I2C bus without address conflicts [R1].
- **Hall effect sensor output:** The chosen sensor outputs a ratiometric analog voltage centered at V_DD/2 when no field is present. At 3.3V supply, the quiescent output is 1.65V [R2].
- **Display SPI initialization:** The ST7365P controller requires a specific initialization command sequence before accepting display data [R3].

**References used this session:** ADS7128 datasheet [R1], Hall effect sensor datasheet [R2], ST7365P datasheet [R3], DFRobot_GDL library source [R4].

---

## Entry 8 — 2026-02-15: Display Connector Investigation

**Objectives:** Determine whether an existing DSI touch display from a prior project can be reused with the ESP32, and if so, how to wire it.

**Record:**

The display in question uses a GDI ribbon connector, which the ESP32-S3 does not support natively — it would require a separate DSI-to-SPI bridge chip. Upon closer inspection of the display PCB, test pads were found for SPI, I2C, and analog control signals. This meant the display could be driven directly from the ESP32 over hardware SPI without any bridge chip.

Confirmed the display uses an **ST7365P** controller [R3], for which the DFRobot_GDL Arduino library [R4] provides a working high-level driver. The capacitive touch layer uses a **GT911** controller [R5] communicating over I2C.

**Design Decision:** Use the SPI test pads rather than the GDI connector. This eliminated the bridge chip, reduced BOM cost, and allowed a much simpler PCB layout. Trade-off: SPI has lower theoretical bandwidth than DSI, but at the target resolution (480x320) and frame rate, SPI at 40 MHz is more than sufficient.

**References:** ST7365P datasheet [R3], DFRobot_GDL library [R4], GT911 datasheet [R5].

---

## Entry 9 — 2026-02-23: Initial Breadboard Setup

**Objectives:** Assemble the Hall effect + ADS7128 breadboard, validate I2C communication, and measure sensor response to magnets at operating distance.

**Record:**

Assembled the breadboard with 8 Hall effect sensors at 1.5" center-to-center spacing (matching the planned tile dimensions) and one ADS7128 on its QFN breakout board connected to the ESP32 over I2C.

**Debugging log:**

| Problem | Root cause | Resolution |
|---|---|---|
| ADC not responding on I2C bus | Wrong I2C address in firmware (ADDR pin state not accounted for) | Measured ADDR pin voltage, recalculated address to `0x10`, updated firmware |
| ADC intermittently dropping off bus | Cold solder joint on QFN breakout pad | Reflowed with additional flux; confirmed continuity |

After fixes, the ADC responded correctly on the bus and all 8 channels returned valid readings.

**Sensor sensitivity test:** The magnets ordered were weaker than expected. Reliable detection required nearly direct contact between magnet and sensor surface. This was below the target operating distance of approximately 3mm through the tile PCB substrate.

**Action item:** Order stronger magnets (higher grade NdFeB). Risk item — if magnets cannot produce a sufficient field at operating distance, the sensing architecture may need to change.

**Fig. 2** — Breadboard test setup showing 8 Hall effect sensors, ADS7128 breakout, ESP32 dev board. *(See `../Danny/hall_effect_sensors_on_breadboard.png` and `../Danny/connected_breadboards_for_esp32_testing.png`)*

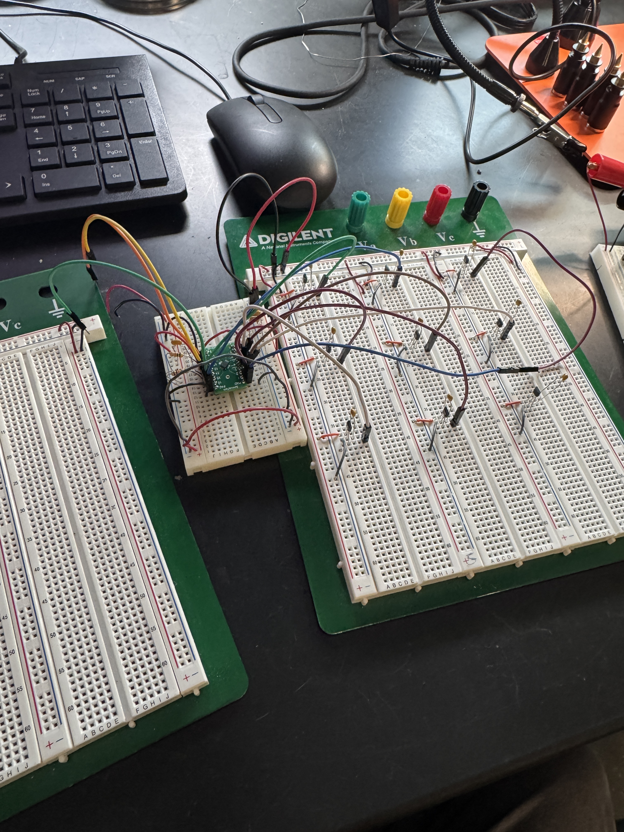
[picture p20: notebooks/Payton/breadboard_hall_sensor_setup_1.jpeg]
Breadboard with Hall effect sensors, ADS7128 breakout, and ESP32 dev board


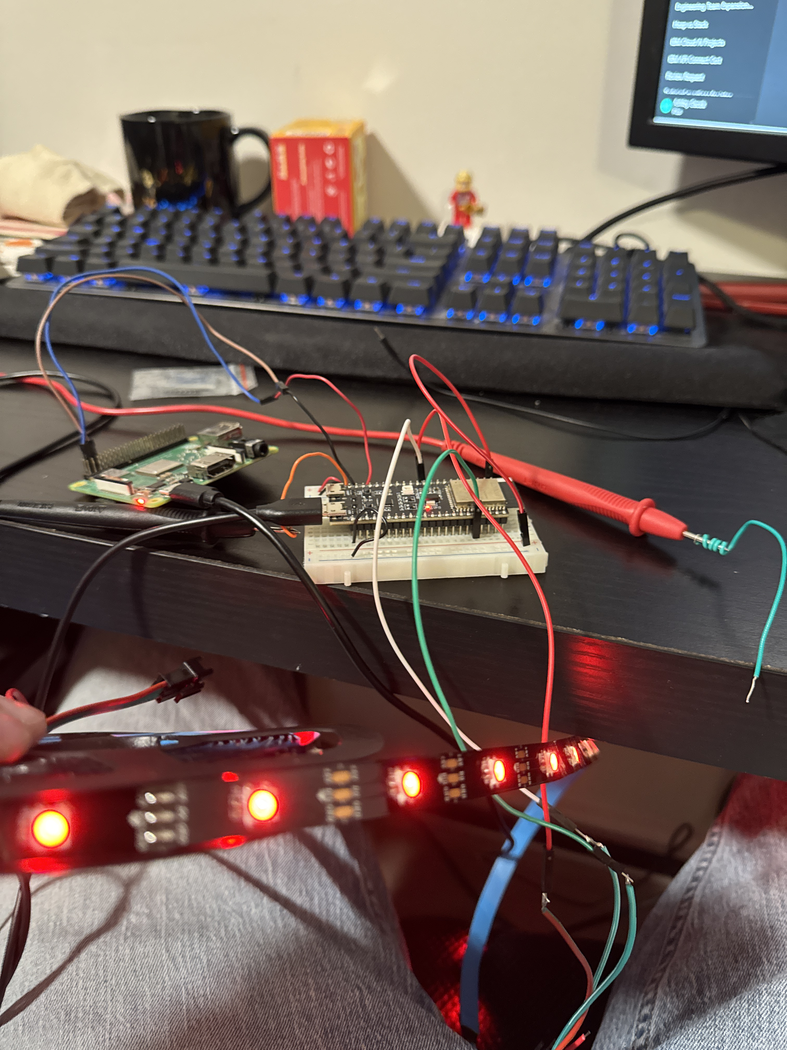
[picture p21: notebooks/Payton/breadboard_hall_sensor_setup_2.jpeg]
Second view of breadboard Hall effect sensor test setup


---

## Entry 10 — 2026-03-05: Breadboard Demo Planning

**Objectives:** Plan the March 9 demo deliverables and assign tasks for the pre-Spring Break period.

**Record:**

Agreed to demonstrate three capabilities on March 9:

1. ADC-based piece detection on all 8 sensors simultaneously
2. Per-sensor identification with LED visual feedback
3. Successful ESP32 programming over USB

Assigned tasks for Spring Break:
- **Payton:** Breadboard firmware, LED driver
- **Danny:** PCB schematic review, component placement
- **Quinn:** Display driver initial code, tile PCB layout

Success criteria for Spring Break: PCB files ready to send to fab, display initialization working on dev board.

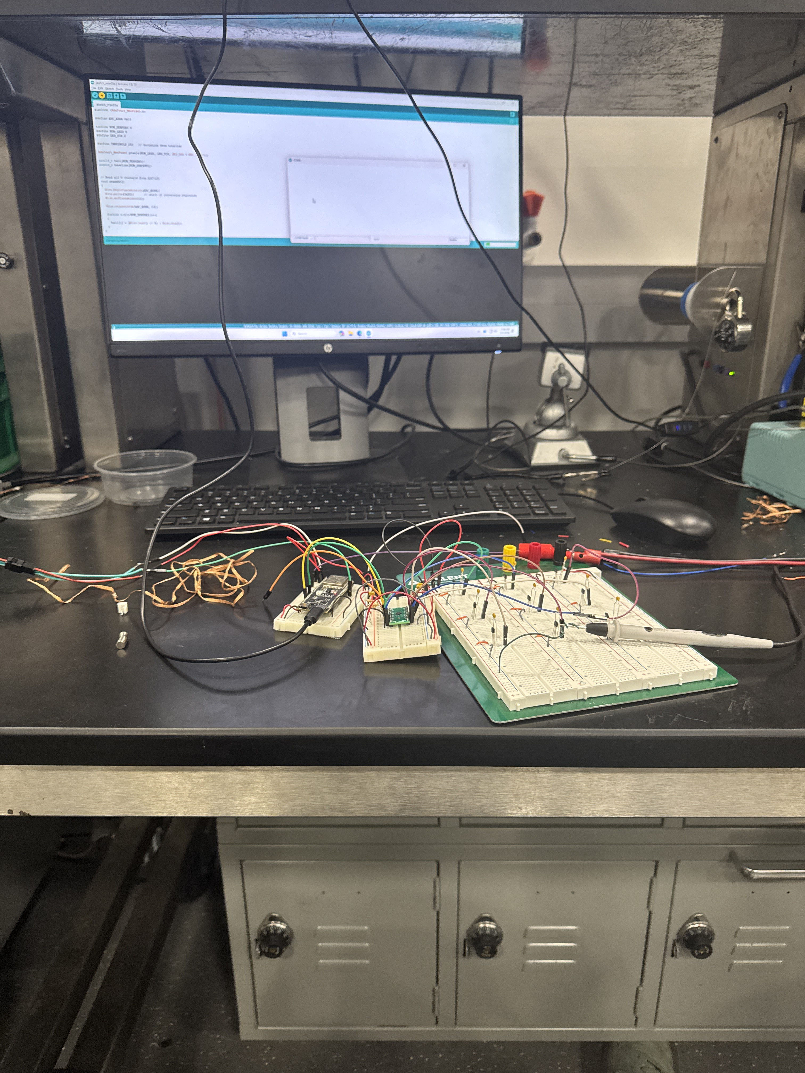
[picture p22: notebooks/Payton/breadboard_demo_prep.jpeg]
Breadboard demo preparation setup


---

## Entry 11 — 2026-03-09: Breadboard Demo

**Objectives:** Demonstrate Hall effect sensing and LED response to course staff.

**Record:**

Demonstrated piece detection across all 8 sensors with real-time LED feedback. The firmware polled the ADS7128 over I2C in a tight loop, compared each channel reading against a fixed threshold, and drove the LED array accordingly.

**Test setup:**
- I2C bus: GPIO 21 (SDA), GPIO 22 (SCL), 100 kHz
- Threshold: 300 counts above/below 2048 midpoint (12-bit ADC, 3.3V ref)
- Sensors: spaced at 1.5" centers, magnets held at approximately 2mm above sensor

**Result:** All 8 sensors responded correctly and independently. Magnetic crosstalk between adjacent sensors was not observed at 1.5" spacing. Professor Fliflet noted this was a successful validation of the sensing approach.

**Key validation:** ADS7128 + Hall effect combination is viable as the sensing layer for the full 64-square board, provided the magnets are strong enough at operating distance.

---

## Entry 12 — 2026-03-24: Main PCB Soldering

**Objectives:** Assemble the first main PCB using reflow soldering and validate through inspection and continuity checks.

**Record:**

Assembly process:
1. Applied solder paste through stencil
2. Placed SMD components by hand (ESP32 module, ADS7128 chips, passives, connectors)
3. Ran board through reflow oven

Post-reflow inspection checklist:
- Visual inspection for bridges — none found on critical nets
- Continuity check: power rails, ESP32 module connections, ADS7128 footprints, display header, programming header
- No cold joints found on first pass

This marked the transition from prototype to production hardware. From this point forward all firmware development targeted the custom PCB.

**Fig. 3** — Main PCB reflow soldering setup. *(See `../Danny/reflow_soldering_main_pcb.png`)*

[main_pcb_reflow_bringup_1.dng](main_pcb_reflow_bringup_1.dng) — Main PCB after reflow, photograph 1 (RAW)

---

## Entry 13 — 2026-03-25: WiFi and API Driver Bringup

**Objectives:** Write the WiFi connection and HTTPS API communication layers, targeting the ESP32-S3 on the custom PCB.

**Record:**

Designed a two-layer network architecture to keep transport details out of the game loop:

**Layer 1 — `wifi_driver`**
- Wraps ESP32 `WiFi` library
- Connects to network by SSID/password with retry loop (up to 40 attempts, 500ms between attempts)
- Exposes `bool wifiConnect(ssid, password)` and `bool wifiIsConnected()`

**Layer 2 — `api_connect`**
- Uses `WiFiClientSecure` + `HTTPClient` for HTTPS
- TLS validation: Amazon Root CA 1 PEM certificate embedded directly in source (the ESP32 has no system certificate store) [R6]
- Exposes: `fetchGameState()`, `pushFENState()`, `sendHeartbeat()`, `resetGame()`, `sendMessage()`, `fetchBestMove()`

**Design Decision:** Hardcode the Amazon Root CA 1 certificate rather than disabling TLS verification. Skipping verification would expose the device to man-in-the-middle attacks on any network. The certificate is valid until 2038, which exceeds the expected product lifetime.

**Design Decision:** The `api_connect` layer returns structured result types (`GameStateResult`, `ApiResult`, etc.) rather than raw JSON. Parsing happens once at the boundary; the game loop works with typed values instead of string dictionaries.

**References:** AWS API Gateway HTTPS setup [R6], ESP32 WiFiClientSecure documentation [R7].

---

## Entry 14 — 2026-03-27: First Flashing of Main PCB

**Objectives:** Flash firmware onto the assembled main PCB and validate that the ADC driver works on real hardware.

**Record:**

**Debugging log:**

| Attempt | Problem | Root cause | Resolution |
|---|---|---|---|
| 1 | Board would not enumerate over USB | PCB resting on metallic solder stencil causing shorts on bottom pads | Lifted board off stencil; no damage |
| 2 | ADC chips not responding on I2C | Firmware used default ESP32 I2C pins instead of PCB-routed `SDA_DAQ`/`SCL_DAQ` | Updated pin definitions to GPIO 38 (SDA) / GPIO 39 (SCL) |
| 3 (success) | All 8 ADS7128 chips responded correctly | — | — |

This confirmed the PCB layout, routing, and component placement had translated correctly from the breadboard prototype. The custom I2C pin assignment (`Wire1` on GPIO 38/39) became a permanent fixture of the hardware abstraction.

**Additional discussion:** Agreed to use individual tile PCBs (designed by Quinn) to mount Hall effect sensors under each square. Preferred over flexible ribbon cables or point-to-point wiring for consistent sensor orientation and a clean mechanical interface.

[main_pcb_reflow_bringup_2.dng](main_pcb_reflow_bringup_2.dng) — Main PCB during early firmware bringup, photograph 2 (RAW)

---

## Entry 15 — 2026-04-02: Initial Firmware Structure Commit

**Objectives:** Refactor test code into a modular production firmware structure.

**Record:**

Split firmware into clearly separated modules:

| Module | File(s) | Responsibility |
|---|---|---|
| WiFi | `wifi_manager.cpp/.h` | Connect, scan, credential UI |
| API | `api_connect.cpp/.h` | All HTTPS communication |
| Display | `display_driver.cpp/.h` | All screen rendering |
| ADC sensing | `ADC_driver.cpp/.h` | ADS7128 driver, FEN assembly |
| Game logic | `gamelogic.cpp/.h` | Chess rule validation |
| Game loop | `gameloop.cpp/.h` | FSM game controller |
| Main sketch | `ChessBoard.ino` | Hardware init, touch dispatch, `loop()` |

This was the first commit where the project resembled an integrated embedded application. Each module had a defined public interface; the main sketch was not permitted to reach into subsystem internals.

---

## Entry 16 — 2026-04-06: Structure Refactor

**Objectives:** Clean up headers, simplify shared state exposure, and tighten display and API interfaces.

**Record:**

Cleanup items completed:
- Removed redundant `extern` declarations
- All display functions grouped into `display_driver.h`; callers no longer include internal headers
- API result types moved to a shared header so `gameloop.cpp` does not include `api_connect.h` directly
- Consistent naming convention applied across all function signatures

No functional changes. This session was preparatory for the integration phase, where sensing, UI, and networking would all need to operate concurrently inside the same control loop.

---

## Entry 17 — 2026-04-07: Display Driver and WiFi Manager UI

**Objectives:** Build the board renderer, implement dirty-cell caching for performance, and add the runtime WiFi selector UI.

**Record:**

**Display initialization issue:** The ST7365P initialized in portrait mode by default, rendering all content rotated 90 degrees. Fixed by setting the `MADCTL` register value for landscape orientation [R3].

**Board renderer design:**
- 8x8 grid of 32x32 pixel squares, cream and brown alternating colors
- Pieces rendered as filled circles with centered piece letter; white pieces: white disc, black rim; black pieces: black disc, grey rim

Touch coordinates from GT911 are in portrait space and must be transformed to landscape. With display width W = 480 and height H = 320:

    tx = 479 - raw_y      (Eq. 17.1)
    ty = raw_x            (Eq. 17.2)

**Performance — dirty-cell cache:**

Redrawing all 64 squares every loop at 40 MHz SPI:

    t_full_redraw = 64 * 32 * 32 * 16 bits / 40,000,000 bps ≈ 52 ms   (Eq. 17.3)

This exceeded the acceptable loop latency for touch response. Solution: a 64-bit dirty bitfield (`s_dirtyCells`) where bit i is set only when square i changes. Per-loop redraw cost drops to (number of changed squares) × (per-square cost).

**WiFi Manager UI:**
- Scans nearby networks and displays SSID list on screen
- Player taps a network, enters password via on-screen keyboard
- Credentials passed to `wifi_manager.cpp` for connection attempt

**References:** ST7365P MADCTL register [R3], GT911 coordinate system [R5].

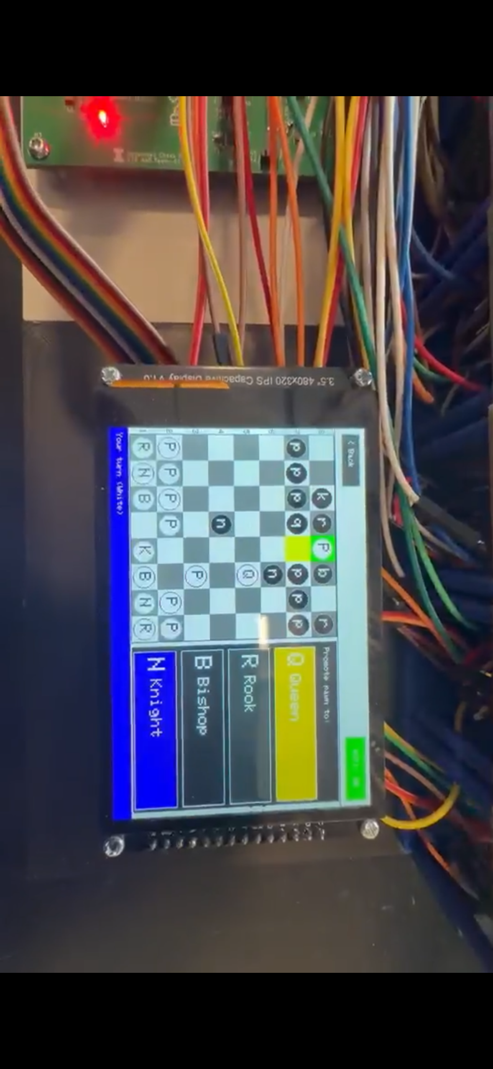
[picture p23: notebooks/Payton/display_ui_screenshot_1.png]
Display UI screenshot 1 — game screen


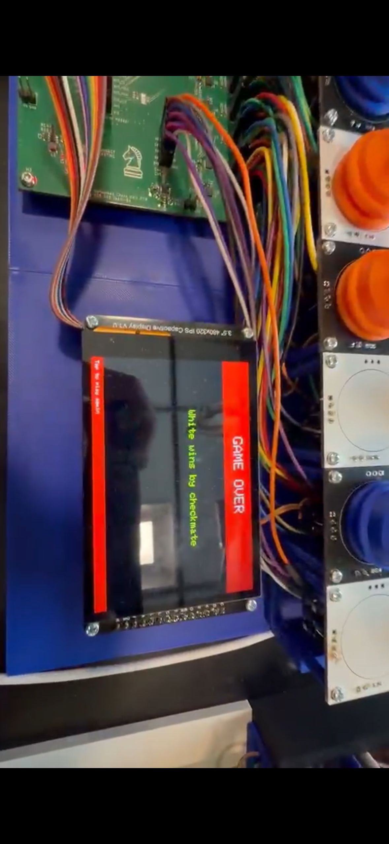
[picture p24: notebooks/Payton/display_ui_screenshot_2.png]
Display UI screenshot 2 — game screen


---

## Entry 18 — 2026-04-10: Tile PCB Soldering

**Objectives:** Assemble all tile PCBs and verify sensor orientation consistency.

**Record:**

Each tile PCB carries one Hall effect sensor, two bypass capacitors, and a connector. 64 tiles required for a full board.

Assembly process per tile:
1. Solder Hall effect sensor in correct orientation (flat face toward playing surface)
2. Solder bypass capacitors on supply pins
3. Solder column bus connector

**Critical check:** Sensor orientation must be consistent across all 64 tiles. The firmware encodes polarity as white (N-pole) vs black (S-pole) vs empty. A single reversed sensor would permanently misidentify piece color on that square.

At this scale (64 repetitions of the same task), procedural consistency matters more than individual skill. Used the tile support print as an assembly jig to hold each PCB at the correct angle during soldering.

**Fig. 4** — Tile PCB assembly. *(See `../notebooks/Quinn/TilePCB_soldered.jpeg` and `../notebooks/Quinn/TilePCB_assembly.jpeg`)*

[board_tiles_partial_assembly_1.dng](board_tiles_partial_assembly_1.dng) — Board with tiles partially installed, photograph 1 (RAW)

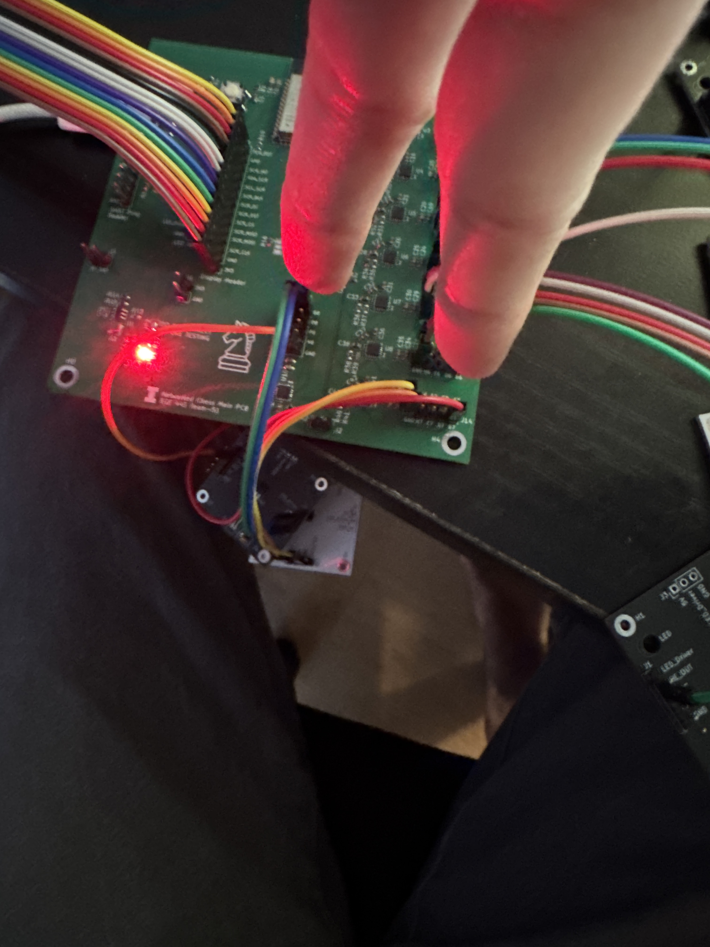
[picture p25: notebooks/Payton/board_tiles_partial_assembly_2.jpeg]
Board with tiles partially installed — photograph 2


---

## Entry 19 — 2026-04-15: Test Mode and Move Validation Integration

**Objectives:** Add a hardware test mode to the main firmware and formally integrate the move validation engine.

**Record:**

Added a `BOARD_TEST` screen state to `ChessBoard.ino` that renders raw ADC counts for all 64 squares. This allowed hardware validation without swapping firmware images.

Move validation (`gamelogic.cpp`) integrated and connected to the game loop. The validator takes two FEN strings (before and after a move) and returns the validated result FEN or `"Invalid Move"`. Handles: castling, en passant, promotion, check, checkmate, stalemate.

**Design Decision:** Move validation runs entirely on the ESP32-S3, not on the server. This keeps rule enforcement at the device, prevents invalid moves from reaching the backend, and means the server can be stateless with respect to chess rules — it only stores and forwards FEN strings.

---

## Entry 20 — 2026-04-16: ADC Driver and Column Mapping

**Objectives:** Complete the production ADC driver with correct column-to-chip mapping and validated detection thresholds.

**Record:**

Eight ADS7128 chips at I2C addresses `0x10`–`0x17` on `Wire1` at 100 kHz. Each chip handles one column of 8 squares.

**Physical column-to-chip mapping:**

Due to PCB routing constraints, file a–h does not map linearly to chip addresses 0x10–0x17:

| File | a | b | c | d | e | f | g | h |
|---|---|---|---|---|---|---|---|---|
| Chip offset | 7 | 6 | 5 | 4 | 0 | 1 | 2 | 3 |

Implemented as `ADC_COL_TO_CHIP[8] = {7, 6, 5, 4, 0, 1, 2, 3}`.

**Threshold derivation:**

ADS7128 is a 12-bit ADC, 3.3V reference. LSB voltage:

    Delta_V_LSB = 3.3 V / 4096 ≈ 0.806 mV/count                    (Eq. 20.1)

Baseline (no magnetic field): 2048 counts (midpoint at V_DD/2). Threshold set at ±300 counts:

    Delta_V_threshold = 300 * 0.806 mV ≈ 242 mV                     (Eq. 20.2)

Measured noise floor: < 20 counts RMS. Measured signal from NdFeB magnets at rated height: 400–800 counts.

Signal-to-noise ratio at minimum signal:

    SNR = 400 counts / 20 counts = 20                                (Eq. 20.3)

The 300-count threshold provides comfortable margin above noise with headroom below the minimum expected signal.

| ADC reading | Encoding |
|---|---|
| > 2348 | White piece — N-pole (`P`) |
| < 1748 | Black piece — S-pole (`p`) |
| 1748–2348 | Empty square (`.`) |

**I2C scan time estimate:**

Each channel read: ~3 I2C transactions (register select + 2-byte data read):

    t_transaction ≈ (3 * 18 bits) / 100,000 bps = 540 µs             (Eq. 20.4)

Full board scan (64 channels):

    t_scan = 64 * 540 µs ≈ 34.6 ms                                   (Eq. 20.5)

Within the 50ms loop budget, leaving ~15ms for display and network operations.

**Fig. 5** — ADC testing setup on main PCB. *(See `../Danny/adc_testing_setup.png`)*

---

## Entry 21 — 2026-04-21: Full System Integration

**Objectives:** Connect ADC sensing, display renderer, WiFi/API layer, and move validation into a single FSM-driven control loop.

**Record:**

Added `gameloop.cpp` implementing a 12-state FSM. An FSM was necessary because gameplay involves many distinct waiting conditions that cannot be safely managed with simple flags.

**FSM state transitions (Fig. 6):**

```
WAIT_FOR_GAME_START
  |--(create)--> GAME_INITIALIZATION --> BOARD_SYNC
  '--(join)----> JOIN_POLLING       --> BOARD_SYNC
                                           |
                                   LOCAL_TURN_WAIT_FOR_BOARD
                                           |
                                   LOCAL_TURN_VALIDATE
                                     |            |
                                  (valid)      (invalid)
                                     |            |
                                LOCAL_TURN_CONFIRM  <-- back to WAIT
                                  |         |
                              (confirm)  (cancel)
                                  |         |
                             SEND_STATE    WAIT_FOR_BOARD
                                  |
                         WAIT_FOR_REMOTE_MOVE
                                  |
                         APPLY_REMOTE_MOVE
                                  |
                         LOCAL_TURN_WAIT_FOR_BOARD (next turn)
                                  |
                            GAME_END (checkmate / stalemate / timeout)
```

**Fig. 6** — FSM state transition diagram for game controller (`gameloop.cpp`).

**State tracked by game manager:**
- Committed FEN, pending FEN
- Castling rights, en passant square, half-move clock
- Server version number (optimistic concurrency)
- Timer state (mode, remaining time per side)
- AI difficulty setting

**References:** FEN notation standard [R8].

Full system integration test — board and display running together

---

## Entry 22 — 2026-04-22: Physical-to-Logical FEN Translation

**Objectives:** Implement the algorithm that converts a raw physical board reading (occupancy + polarity only) into a valid logical chess FEN.

**Problem statement:** Hall effect sensors report occupancy and polarity only — not piece type. A reading can say "white piece on e4" but not whether it is a rook, bishop, or queen. The logical FEN requires full piece type information.

**Record:**

**Algorithm — `cgm_physicalToLogicalFEN()`:**

1. Convert the last committed logical FEN to an expected physical board (all white pieces → `P`, all black → `p`, empty → `.`).
2. Compare expected physical board against new physical reading. Count changed squares.
3. If changed count > 4: reject as ambiguous.
4. If only departure squares changed and no arrival appeared: **piece-in-air** case — wait without committing.
5. For normal moves: clear departure squares. Map arrival squares back to the most likely committed source piece of the correct color at the departure square.

**Special cases:**

| Case | Detection criterion | Handling |
|---|---|---|
| Castling | 4-square change (king + rook both move) | King movement direction determines kingside vs queenside |
| En passant | 3-square change (pawn departs, pawn arrives, captured pawn disappears from adjacent square) | Captured pawn removed from FEN at the en passant square |
| Promotion | Pawn disappears from 7th rank, piece appears on 8th rank | FSM enters `LOCAL_TURN_PROMOTION`; piece type from touchscreen picker |

**Design Decision:** The algorithm is inherently stateful — it is always a diff operation against the last known valid logical state. It cannot work from a single snapshot alone.

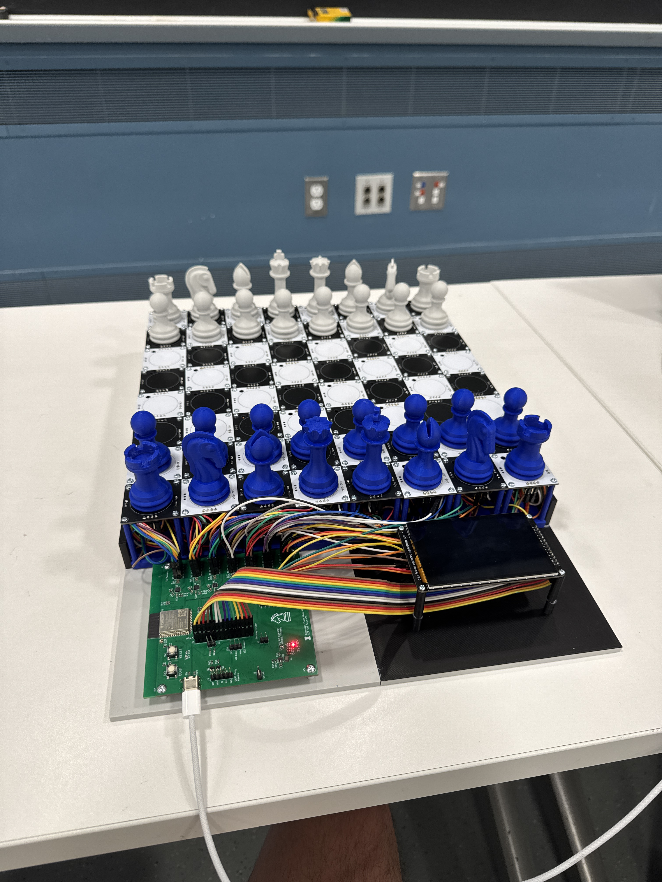
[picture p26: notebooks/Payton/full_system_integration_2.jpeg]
Full system integration test — photograph 2


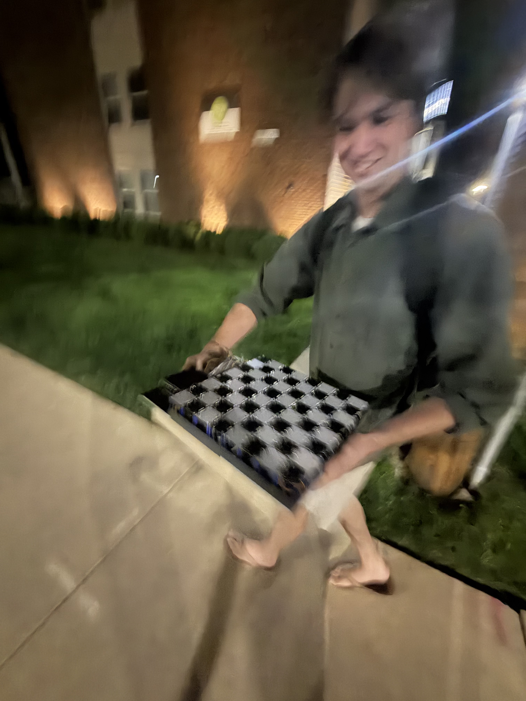
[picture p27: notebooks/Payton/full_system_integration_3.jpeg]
Full system integration test — photograph 3


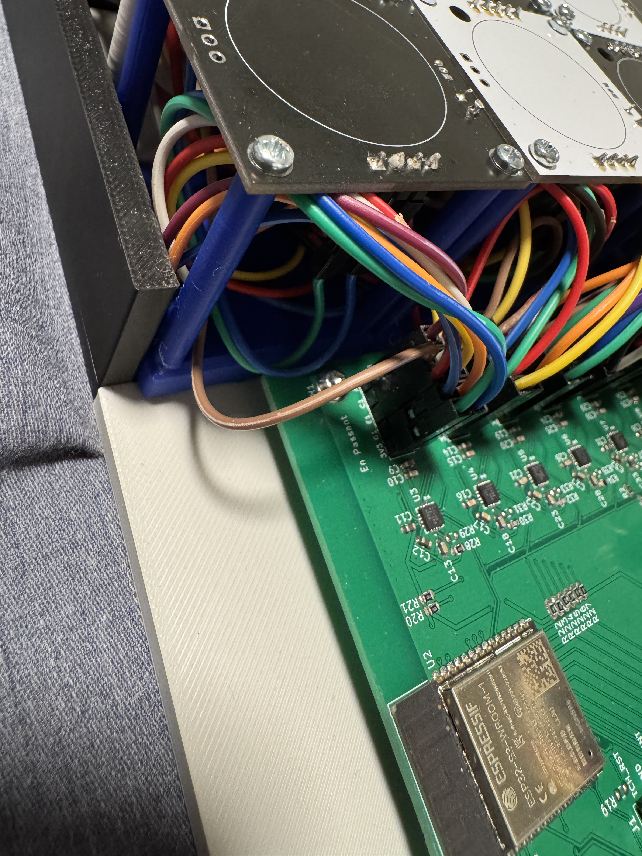
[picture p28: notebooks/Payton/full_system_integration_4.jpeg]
Full system integration test — photograph 4


---

## Entry 23 — 2026-04-23: Integration Cleanup and Promotion Logic

**Objectives:** Tighten interaction between main sketch, display, and game loop; add promotion handling and edge-case testing menu.

**Record:**

Promotion: when the physical-to-logical translator detects a pawn arriving on the back rank, the FSM transitions to `LOCAL_TURN_PROMOTION`. An overlay appears on the touchscreen showing Q, R, B, N. The player's selection completes the FEN.

Edge-case testing menu (`EDGE_CASE_TEST` screen state) loads preset board positions:
- Standard starting position
- En passant available
- Both castling sides available
- Pawn on 7th rank (promotion about to trigger)
- King in check

This menu was critical for demo rehearsal — many important chess rules are rare in normal play but had to work correctly in front of the examiner.

---

## Entry 24 — 2026-04-23: Home WiFi Bringup

**Objectives:** Validate full firmware stack on a real home WiFi network outside the lab.

**Record:**

Successfully connected board to home WiFi, fetched game state from AWS, and completed a full move round-trip. Proved:
- TLS certificate validation works on a non-university network
- API endpoint is reachable from arbitrary networks
- WiFi manager UI correctly stores and retries credentials

This also isolated the university WiFi issue (Entry 25) as a MAC address registration problem, not a firmware bug.

---

## Entry 25 — 2026-04-23: Mock Demo

**Objectives:** Demonstrate full gameplay to TA; identify remaining issues before the final demo.

**Record:**

**Issue encountered:** Second board could not connect to IllinoisNet. The WiFi manager could see the network and attempt connection, but the university's policy was silently rejecting the unregistered MAC address.

**Resolution:** Switched to personal hotspot for the demo. Demonstrated full gameplay flow:
- Move detection and validation
- Display update on both boards
- Network handoff: local board POSTs move, remote board polls and applies it
- Chat messaging between boards
- AI hint feature

After the demo, registered the second board's MAC address through the university self-registration portal. Confirmed connection to IllinoisNet on next attempt. Played a full game between both boards over the university network — all features worked correctly.

**Fig. 7** — Two-board networked game in progress during mock demo. *(See `../Danny/mock_demo.png`)*

---

## Entry 26 — 2026-04-24: Mock Presentation

**Objectives:** Run through a shortened final presentation and collect TA feedback.

**Record:**

TA feedback:
- Reduce text density on slides; replace text with diagrams
- Simplify block diagram layout with clearer labels
- Each speaker should cover only the subsystems they were primarily responsible for

Updates made to slides:
- Replaced FSM description slide with Fig. 6 (state transition diagram)
- Replaced FEN translation description with annotated step-by-step figure
- Moved detailed API field descriptions to a backup/appendix slide

---

## Entry 27 — 2026-04-26: Timed Modes, Versus AI, Hints, and Messenger

**Objectives:** Add game clocks, versus-AI mode, Stockfish hints, and in-game chat.

**Record:**

**Timer modes:**

| Mode | Budget per side |
|---|---|
| Unlimited | No clock |
| Rapid | 10 minutes (600,000 ms) |
| Bullet | 5 minutes (300,000 ms) |

Clocks tracked on-device using `millis()`. The server stores only the timer mode and initial budget. When a clock expires, the board calls `POST /games/1/timeout` with the losing color; the server sets `gameResult` to `white_timeout` or `black_timeout`.

**Versus AI:** Reuses the remote-move path. The server's Lambda function runs Stockfish at the configured depth:

| Difficulty | Stockfish depth |
|---|---|
| Easy | 2 |
| Medium | 5 |
| Hard | 12 |

**Hints:** `POST /games/1/hint` with current FEN returns the Stockfish best move UCI string. Firmware highlights source and destination squares. Each game grants 3 hints.

**Messenger:** Chat messages stored as a list in DynamoDB. Boards poll `GET /games/1/messages` every 5 seconds and display the last 3 messages in a right-panel chat window.

---

## Entry 28 — 2026-04-26: UI Bug Fixes and Polish

**Objectives:** Fix layout and visual issues in the game screen after the large feature commit.

**Record:**

Issues fixed:

| Bug | Root cause | Fix |
|---|---|---|
| Timer display overflow when < 1 min | Width not recalculated for shorter MM:SS string | Recalculate display width dynamically per draw call |
| Chat panel not clearing on new game | Stale messages from previous game persisted in render cache | Clear chat cache on every `GAME_INITIALIZATION` entry |
| Board sync overlay blended into cream squares | Highlight color too similar to board background | Changed highlight to bright cyan |
| Move confirmation buttons misaligned | Screen state transition did not reinitialize button coordinates | Reinitialize layout coordinates on every `LOCAL_TURN_CONFIRM` entry |

---

## Entry 29 — 2026-04-27: Timer and AI Fixes

**Objectives:** Fix edge cases in timed modes, AI mode behavior, and check indicator display.

**Record:**

Fixes:

| Issue | Root cause | Fix |
|---|---|---|
| Timer did not pause during BOARD_SYNC | No pause on FSM entry to `BOARD_SYNC` | Added timer pause on `BOARD_SYNC` entry, resume on exit |
| AI move display lag | Board transitioned to `LOCAL_TURN_WAIT_FOR_BOARD` before display updated | Added display refresh call on `APPLY_REMOTE_MOVE` entry |
| Check indicator not clearing after check resolved | `drawCheckAlert(false)` not called on FSM transitions | Added `drawCheckAlert(false)` on every transition out of `LOCAL_TURN_VALIDATE` |

---

## Entry 30 — 2026-04-27: Final Demo Preparation

**Objectives:** Script the demo game, assign presenter roles, confirm all edge cases trigger correctly in sequence.

**Record:**

Scripted game chosen to demonstrate the most important chess edge cases in 11 moves:

| Move | Notation | Feature demonstrated |
|---|---|---|
| 3 | exd6 e.p. | En passant (3-square change detection) |
| 4 | dxc7 | Standard capture |
| 5 | cxb8=Q | Pawn promotion with touchscreen picker |
| 10 | O-O-O | Queenside castling (4-square change detection) |
| 11 | Qh5# | Checkmate detection and game-over screen |

Full move sequence:
```
1. e4 f6  2. e5 d5  3. exd6 e.p. Bd7  4. dxc7 g5
5. cxb8=Q Rxb8  6. Nc3 a6  7. d3 a5  8. Bd2 a4
9. Qg4 a3  10. O-O-O b6  11. Qh5#
```

Presenter assignments:
- **Payton:** ADC architecture, sensing thresholds, physical-to-logical FEN translation, FSM game loop, WiFi/API layer
- **Danny:** PCB design, tile PCB, hardware assembly
- **Quinn:** Display driver, UI, enclosure design

---

## Entry 31 — 2026-04-27: Second Board Assembly and Bringup

**Objectives:** Complete assembly of the second board and confirm it is ready to flash and test.

**Record:**

Lessons applied from the first board assembly:
- Pre-checked all QFN pads for continuity before reflow
- Used improved stencil alignment jig to reduce paste smearing
- Verified sensor orientation on all 64 tiles before final installation

Confirmed the second board came up correctly on first flash attempt.

**Fig. 8** — Second board fully assembled with all 64 tile PCBs installed. *(See `quarter_of_board_assembled.png` and `full_board_assembled.png`)*

Both boards now functional and ready for the scripted demo.

---

## Entry 32 — 2026-04-29: Final Demo

**Objectives:** Demonstrate the full system to Professor Fliflet with both boards running on separate networks.

**Record:**

Played the scripted game in full. All planned edge cases triggered and resolved correctly:

| Edge case | Result |
|---|---|
| En passant (move 3) | 3-square change correctly identified; FEN updated with captured pawn removed |
| Promotion (move 5) | Picker overlay appeared automatically; queen placed correctly in FEN |
| Castling (move 10) | 4-square change correctly identified as queenside castle |
| Checkmate (move 11) | Both boards displayed game-over screen simultaneously |

Additional demonstrations completed:
- WiFi reconnection: disconnected one board mid-game; it reconnected and resynced to current game state automatically
- AI hint: highlighted suggested move on board and display
- Versus AI: engine played correct responses without a second physical board present

**Examiner questions and answers:**

| Question | Answer |
|---|---|
| How does the board handle a player picking up a piece and putting it back without moving? | Piece-in-air filter in `cgm_physicalToLogicalFEN` detects departure without arrival and waits; no move is committed until a piece lands on a new square |
| How does FEN orientation work when playing as black? | `localIsWhite` flag in `readBoardFEN()` mirrors the entire board reading; rank 1 always maps to the local player's back rank |
| What if both boards POST a move simultaneously? | Server uses `expectedVersion` optimistic concurrency; the second POST receives HTTP 409 with current state; the losing board re-fetches and retries |

**Fig. 9** — Both boards running the final demo. *(See `../Danny/working_single_board_game.png`)*

---

## Entry 33 — 2026-04-30: Final Presentation Preparation

**Objectives:** Polish slides, rehearse timing, practice the physical-to-logical FEN translation explanation.

**Record:**

Slide edits:
- Cut FSM state diagram to show only the 7 most common transitions (full diagram moved to backup slides)
- Reformatted to UIUC ECE presentation template
- Added annotated figure for the en passant 3-square change detection

Practiced the physical-to-logical FEN translation explanation with a physical board, as this was the most technically dense section and most likely to generate follow-up questions.

---

## Entry 34 — 2026-05-01: Final Presentation

**Objectives:** Present and defend the completed project.

**Record:**

Sections presented:
1. **ADC driver and threshold scheme** — Eq. 20.1 through 20.5; column mapping table
2. **Physical-to-logical FEN translation** — algorithm walkthrough with en passant and castling examples
3. **FSM game loop** — Fig. 6; discussion of why an FSM is necessary vs simple flags
4. **WiFi/API layer** — TLS certificate pinning, heartbeat mechanism, optimistic concurrency versioning

Additional questions received:

| Question | Answer |
|---|---|
| Why AWS Lambda + DynamoDB rather than a persistent server? | Lambda scales to zero when no games are active, eliminating idle cost. DynamoDB provides durability without managing a database server. |
| How is move history used? | Stored server-side for auditing; boards only need the latest FEN and version number to operate. |

---

## Entry 35 — 2026-05-04: Awards Ceremony

**Objectives:** Attend ECE 445 awards ceremony.

**Record:**

The project received an **Honorable Mention** at the ECE 445 awards ceremony held in ECEB. Attended with Quinn and Danny; certificates collected.

ECE 445 awards ceremony — honorable mention

---

## References

| # | Source |
|---|---|
| R1 | Texas Instruments, *ADS7128 8-Channel, 12-Bit, I2C Analog-to-Digital Converter with GPIO*, SBAS869C, 2021. |
| R2 | Allegro MicroSystems, Hall effect sensor datasheet (part number per BOM). |
| R3 | Sitronix, *ST7365P Color LCD Controller Datasheet*, Rev. 1.0. |
| R4 | DFRobot, *DFRobot_GDL Arduino Library*, GitHub, 2023. |
| R5 | Goodix, *GT911 5-Point Capacitive Touch Controller Datasheet*, Rev. 1.1. |
| R6 | Amazon Web Services, *Amazon Root CA 1*, valid through 2038. |
| R7 | Espressif Systems, *ESP-IDF WiFiClientSecure Documentation*, v5.x. |
| R8 | FIDE Laws of Chess, Appendix C — Algebraic Notation and FEN, 2023. |

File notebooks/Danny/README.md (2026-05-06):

# Danny's Worklog

# 2026-01-21 - First Group Meeting
Met with the team for the first time to discuss possible project ideas. We each came up with an idea to post to the web board. Payton suggested two physical chess boards that could play each other over the internet. We liked the chess board idea the most because it felt the most realistic and interesting, but we still posted all three ideas to get feedback from course staff.

# 2026-01-24 - Getting Ideas on Paper
Met with the team again to narrow down the project idea and start putting more details together. We officially decided to move forward with the Networked Physical Chess Board for Remote Play. The main idea was to have two physical boards connected over the internet so two players could play remotely. We also decided that LEDs would show the opponent’s moves and that the board would include a touch display UI. We wrote these ideas into an informal document so we could keep track of the early design direction.

# 2026-01-28 - Request for Approval
Worked with the team to write and submit our Request for Approval early for extra credit. We wrote out the problem we wanted to solve, our proposed solution, the main subsystems, our criterion for success, and the major components we planned to use. At this point we were planning on using Hall effect sensors, an ESP32, an I2C ADC, and a touch screen display.

# 2026-02-02 - Buying Breadboard Parts
Worked on getting our initial breadboard parts ordered. This included Hall effect sensors, magnets, ADCs, and adapters so we could actually test the parts on a breadboard. We had to change our original ADC because it was not in stock, so we switched to the ADS7128. This still gave us the functionality we needed while also being cheaper and easier to get. We also ordered magnets so we could test how sensitive the Hall effect sensors were at different distances.

# 2026-02-10 - Preparing for First TA Meeting
Met with the team to prepare for our first TA meeting. The main focus was getting a better block diagram together so we could explain our project at a high level. We broke the design into the major subsystems and listed the hardware each part would need. This helped us explain how the sensing, display, WiFi, and game logic would all connect.

# 2026-02-11 - First TA Meeting
Met with our TA to go over the initial high-level design. We got mostly positive feedback. There was some confusion at first about how the physical layout of the boards would work, but we talked through it and cleared it up. Overall it seemed like we were moving in the right direction.

# 2026-02-11 - DigiKey Order Issue
There was an issue with our DigiKey order for the breadboard parts. The order had not updated and there was an error when trying to look it up. We contacted DigiKey support and found out that the order had to be placed again. They reimbursed the cost, but they could not speed up shipping. Luckily the parts were still expected to arrive in time for us to use them.

# 2026-02-13 - Project Proposal Document
Finished writing the Project Proposal Document with the team. This document went into more detail than the RFA and included our subsystems, component choices, physical design, and overall plan for the project. It helped turn the early idea into a more concrete design.

# 2026-02-14 - PCB Size Clarification
We needed to figure out the actual PCB size limits before finalizing our hardware design. We found out from Professor Fliflet that we were limited to a 10 cm square PCB. Our original plan was to make one large PCB the size of the chess board, but that was not allowed. We adjusted the plan so the main PCB would hold the MCU, power circuitry, and ADCs. The Hall effect sensors would sit under the individual chess squares and wire back to headers on the main board.

# 2026-02-15 - Display Connector Planning
Worked on figuring out how the display would connect to the rest of the system. Since the display was an important part of the user interface, we needed to make sure the connector and wiring made sense for the ESP32 and our physical board layout. This was mostly planning and checking compatibility so we would not design around a display connection that would be difficult to use later.

# 2026-02-16 - Main PCB Schematics
Worked on the main PCB schematic for the project. The goal was to get the ESP32, ADCs, power, headers, and supporting components connected correctly before routing the board. This was an important step because the main board would become the center of the whole system and connect to the Hall effect sensors under the chess tiles.

# 2026-02-23 - Initial Breadboard Setup
Met with the team for the first time to discuss possible project ideas. We each came up with an idea to post to the web board. I suggested an auto dealer poker machine, another idea was a universal game board with an E-ink display, and Payton suggested two physical chess boards that could play each other over the internet. We liked the chess board idea the most because it felt the most realistic and interesting, but we still posted all three ideas to get feedback from course staff.

# 2026-03-02 - Discussion with Professor Fliflet
Discussed project at Design Review with Professor Fliflet. He suggested we add tolerance section to our design document as well as splitting up the workload in the schedule section between all of our group members. 

# 2026-03-05 - Team Meeting
Met to discuss what needs to be completed by Sunday 03/08 and what needs to be done by the time Spring Break starts. Payton and I tasked with getting the breadboard code done before the Breadboard Demo scheduled for 03/09. Bought wooden enclosre to be used for testing components as we implement them. 

# 2026-03-09 - Magnet Demo
I met with the team to prepare and demo the magentic capabiltiies of our project. This included an array of 9 Hall Effect sensors which I wired to the breadboard to show the proof of concept for our magnetic capabilities. What this entailed was a full connection with the ESP32 and a flashed set of code that triggered LEDs when a magent passed over one of the sensors. Each LED was individually addressable, so hovering a magnet over one of the sensors only turned on its respective LED. This was a very successful demo and really showed what we could do.

# 2026-03-18 - Move Checking API Code
Our boards must check when a move is made whether that move is legal and whether it ends the game. For example, once a move is made maybe the player moved the piece in an illegal way (like moving a knight in a straight line). This is detectable because the checker first makes sure only 2 tiles were changed (source/destination tiles) or 4 tiles (in the case of castling). Once it knows this, it knows the previous board state and new state which means it knows which piece was moved and how it was moved. 

If a move is made and is deemed illegal, the move will not be able to be sent to the opponent and the display will show the move was not valid. This will give the player a chance to move the piece back and move again to make a legal move. 

If the player's move ends the game (checkmate/stalemate/time out) then the game will end for both players and the display will show who the winner/loser is. 

The move checking API relies heavily on one trick; the game board begins in the standard board state at the start of every game. This gives us information on every piece's location from the start. Once a move is made we can only detect one tile losing a piece and another gaining one. We do not know which piece was moved directly, but we do know the previous board (the first being the standard start state) so we can determine exactly which piece was moved and where it moved to. 

Once a legal move is made, if it is a legal move and doesn't end the game then the board state will be condensed into a FEN string (a representation of chess states using just one string) and will be sent over WiFi to the opposing board for it to read. LEDs will light up to display where the player moved which piece and the opponent can make the player's move on their board before being allowed to start making their move. 

The code for this move checking was written such that it can be eventually flashed to the ESP32 using the Arduino IDE. More debugging of this code is necessary and we also will figure out how to connect this string-checking code to the actual physical boards. 

# 2026-03-24 - Main PCB Soldering
The main PCB for our project arrived. I went to the lab to check our components were all present. Once I confirmed everything was there, I began applying solder paste using the PCB stencil. One of the USB connectors we bought isn't exactly what we needed so we may have to order new ones. After applying the paste, placed all the components on the board in the pasted slots. Once that was done, started up the reflow oven following the directions on the wall. Placed PCB in the oven and waited as it coldered our components to the board. Once the board was taken out a shorts check was done and we luckily had no bridging/shorting. Next stpes are to potentially program the board, build the physical chess board itself, and begin writing the backend chess game logic. 

# 2026-04-10 - Tile PCB Soldering
In our project, the tiles of the chess board are going to be individual black/white PCBs with a Hall Effect sensor underneath each one. These tile PCBs arrived and we began soldering them. Each tile has a few components to add. My task was to solder soem of these components to these boards. 

# 2026-04-21 - Completed Single Board
We fully assembled our first board. All the tiles were put in place and the wiring was completed. Next steps will be to work on the software to get a working game between the assembled board and our demo website where we can send and receive moves as an "opponent". 

# 2026-04-22 - Debugging Display + FEN Reading
Spent time debugging issues with the display and how FEN strings were being read and interpreted on the board. The display was not updating correctly after moves, so traced through the code to see where the breakdown was happening between receiving the FEN string and rendering the board state. Adjusted parts of the logic to correctly read FENs from the ADCs. Also worked on making sure the display properly reflects invalid moves and resets correctly when needed. Screen was also rotated incorrectly, so fixed it to face the player. 

# 2026-04-23 - Mock Demo + Working Single Board Game
Held our mock demo with our TA to simulate how the full system will function during presentation. During the demo there was a slight hiccup that prevented us from fully being able to show the working single board. After the demo we worked more and realized we were reading an incorrect MAC address for the board to be able to properly interface with the university WiFi. At this point we successfully got a single board fully working with move detection, validation, and display updates. The board can now detect piece movement, verify legality using our move checking logic, and update the display accordingly. It also correctly displays checkmates as well. This was a big milestone because it shows that the core gameplay loop works on one board. Focus moving forward will be first on printing, soldering, and assembling a second board. Then we will shift focus to syncing two boards together over WiFi and polishing the overall user experience on the displays for the final demo.

# 2026-04-27 - Final Demo Prep
Met with team to discuss what order we will display our functionality in. Also developed a move sequence to show implementations of En Passant, Promotions, Castling, and Checkmate. This way we have a predetermined game we will run through with for the professor to see our full functionality. The move order is as follows:

1. e4 f6
2. e5 d5
3. exd6 e.p. Bd7 (En Passant)
4. dxc7 g5 (Capture)
5. cxb8=Q Rxb8 (Promotion)
6. Nc3 a6
7. d3 a5
8. Bd2 a4
9. Qg4 a3
10. O-O-O b6 (Castling)
11. Qh5# (Checkmate)

We will talk throughout while also playing the game against the two boards. We decided to split the talking points between us to highlight what each of us specialized in this project. 

# 2026-04-28 - Final Presentation Prep
Worked on my portion of the Final Presentation slides today. Included all the information on FEN strings and how move validation works in the backend. Rehearsed a bit alone and then discussed with the team what order we will go in for the final presenting. 

# 2026-04-29 - Final Demo
Demo'd our project to the professor. We accurately showed all the features we intended to, including using the game order above, showing WiFi connections, chat/hint features, and reconnecting if connection goes out. Next step is to finalzie how we will do our Final Presentation. 

# 2026-05-01 - Final Presentation
Presented our Final Presentation to the professor, TA, and peer reviewers. Answered some questions about connectivitiy, physical design process/issues, and how our backend processes moves and validates board states. 

# 2026-05-02 - Final Video
Discussed what should be included and in what order for the final video. Teammates then recorded themselves playing games against each other at their apartments and a voice recording was made explaining the game and moves as they were being made. Submitted this video.

# 2026-05-04 - Awards Ceremony
Selected as an Honorable Mention! Attended awards ceremony in ECEB and picked up our certificate.

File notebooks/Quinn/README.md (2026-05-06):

# January 21, 2026 - First Group Meeting
**Objective**: We are meeting for the first time to try and nail down what we want to do for potential projects. We are going to come up with three ideas, one for each of us to post to the web board. We will hopefully have one that we like the most that we will follow

**What got done**: We came up with a couple different ideas. I came up with the idea to do a universal game board using an E-ink display. Danny came up with the idea to do a auto dealer poker machine. And Payton came up with the idea to do two chess boards that could play each other over the internet. We liked that one the best, but we all posted our ideas to get the course staffs thoughts. 

# January 24th, 2026 - Meeting To Get Ideas On Paper
**Objectives**: Meet to get final ideas of our project and put them on paper.

**What Got Done**: We fully decided on the Networked Physical Chess Board for Remote Play. We decided that we wanted to connect to the internet and have LEDs display the moves the other player made. We would also have a touch display UI. We put these ideas into an informal doc that we could refer to later

# January 28th, 2026 - Wrote RFA
**Objectives**: Write and submit our request for approval early for extra credit.

**What Got Done**: We officially got our idea down on paper and submitted to PACE. We outlined our problem, solution, subsystems, criterion for success, and component selection. 

* Hall effect sensor: [DRV5055A4QDBZR 12.5 mV/mT, ±169-mT Range](https://www.digikey.com/en/products/detail/texas-instruments/DRV5055A4QLPG/9371283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)
* MCU: [ESP-32 (includes Wi-Fi antenna and capability)](https://www.digikey.com/en/products/detail/espressif-systems/ESP32-S3-WROOM-1-N8R8/15295891)
* ADC: [TLA2528IRTER 12-bit, 8-channel, I2C](https://www.digikey.com/en/products/detail/texas-instruments/TLA2528IRTER/12328606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)
* Display: [DSI Touch Screen LCD Display 800x480](https://www.dfrobot.com/product-3025.html)

# February 2nd, 2026 - Buying Breadboard Parts
**Objectives**: Buy our initial breadboard parts like hall effect sensors, magents, and ADCs.

**What Got Done**: We had to change the ADC we picked initially due to lack of stock on Digikey. We opted to change to the [ADS7128IRTER](https://www.digikey.com/en/products/detail/texas-instruments/ADS7128IRTER/12696006) which offers similar performance with less advanced features and a lower cost. We also bought [QFN-16 3x3, 0.5MM DIP ADAPTER](https://www.digikey.com/en/products/detail/schmalztech-llc/ST-QFN-16-3X3-05/24394924) to allows us to use the same package ADC in our breadboard. The [magnets](https://www.digikey.com/en/products/detail/radial-magnets-inc/8195/555329) we bought should be strong enough, but if they are not they give us a base reading of how sensitive the hall effects are to distance.

# February 10th, 2026 - Getting Ready for the First TA Meeting
**Objectives**: We need to have a more concrete diagrams for our first TA meeting of the semester. 

**What Got Done**: The most important part of this was getting a block diagram together that showed our different subsystems. We showed the hardware that each of our subsystems would need. 

# February 11th, 2026 - First TA Meeting
**Objectives**: Get feedback from our TA on our initial high level designs.

**What Got Done**: We got mostly posotive feedback from our TA. There was some confusion from the block diagram about how things would be physically layed out but this was cleared up with some discussion. Overall it seems like we are heading in the righ direction. 

# February 11th, 2026 - Digikey Order Disruption
**Objectives**: The Digikey order for breadboard parts hasn't had any updates and the order has an error looking it up.

**What Got Done**: I called Digikey support and they said there was an error and that I would need to reorder. They are reimbursing for the cost but can not expedite shipping. Fortunatly the parts will still come in time.

# February 13th, 2026 - Finished Writing The Project Proposal Document
**Objectives**: Need to submit our Project Proposal Document.

**What Got Done**: We finished writing this document getting into more detail on specific componenets, subsystems, and physical design. 

# February 14th, 2026 - Need Clarification on PCB size
**Objectives**: We need to understand the constraints of the PCB size we can order.

**What Got Done**: I emailed Professor Fliflit to clarify. He told us that we are limited to 10cm square. Our original idea was to create a single PCB the size of our chess board (12" square), but now we need to find a new strategy. We are now going to do a single board with MCU, power, and ADCs. The hall effect sensors will sit under each game square and wire directly to our headers for the ADC.

# February 15th, 2026 - Figuring Out the Display Connector
**Objectives**: We want to know how to connect our touch display to our ESP32.

**What Got Done**: We have this [touch dispaly](https://www.dfrobot.com/product-3025.html) from an old project Payton was working on. It orginally connects to a Raspberry Pi. However, it connects through a ribbon cable and we need to know if we can use that connector or a different one. We found that the ribbon cable was for a GDI port. This isn't natively supported on the ESP32 and would require a bridge chip or a converter. We decided aginast this because there are also connection points on the screen for SPI, I2C, and other analog control signals. This makes it so that our ESP32 can directly wire to the display through jumper wires. 

# February 16th, 2026 - Main PCB Schematics
**Objectives**: Finish up the main PCB schematic for routing later.

**What Got Done**: For this I knew we needed the ESP32 setup, power regulator, connectors, and ADCs.

For the ESP32 setup I used the [ECE 445 Wiki page](https://courses.grainger.illinois.edu/ece445/wiki/#/esp32_example/index) example board. This has all the proper boot/strapping pins, buttons, and programming circuit. Our final goal is to program and power through USB but to be safe I added this extra UART programming circuit. 

For the power regulator we need to step down 5V to 3.3V. I chose the [TLV62569](https://www.ti.com/lit/ds/symlink/tlv62569.pdf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) for its simplicity and efficiency. The only math needed was for the feedback voltage divider which follows $V_{out}=0.6V(1+\frac{R_1}{R_2})$. The data sheet recommends $R_2=100k\Omega$ for the best transient response time and current consumption. Solving the equation we get $R_1\approx450k\Omega$. This value had to be changed from the original solution so that it fit a standard value. The datasheet then outlines that for $1.8\leq V_{out}$ we need a $2.2\mu H$ indcutor and three output capacitors valued $10\mu F$. I shorted the enable pin with the $V_{in}$ pin so that the regulator is always on. I also added a solder jumper so that we can test the power system first as to not short other parts. For extra debugging I added an LED that will indicate when power is on.

For the [ADCs](https://www.ti.com/lit/ds/symlink/ads7128.pdf) I put them on their own hierarchical sheet for readability. All the ADCs are on an I2C bus and have an alert pin to the ESP32. We don't know if we will use the Alert pin yet or just poll the I2C bus but I added it so we have the option to use it. Each ADC also gets its own I2C address that is assigned through a resistor network between Decap and ADDR pins. I also added decoupling capacitors on the power output pins for the hall effect sensors. I did this because the wires to power the hall effect sensors will be quite long and thus will have a lot of inductance which these capacitors will negate. 

For connectors we chose to use standard pin headers to connect the display and hall effects. We then have a USB-C 2.0 port for 5V power and programming. I also added pin headers for power and I2C probing. 

# February 23rd, 2026 - Initial Breadboard Setup
**Objectives**: We want to set up our breadboard for the upcoming breadboard demo. This means setting up 8 hall effect sensors that connect ot an ADC which goes to our ESP32 dev board. We then want to also connect our LEDs.

**What Got Done**: We get the hardware set up on a large breadboard with hall effects set up 1.5" apart. We soldered the ADC to the breakout board and wired it to the ADC. We had some issues connecting to the ADC but were able to resolve it by reconfiguring the ESP and resoldering our ADC. We also found that our magnets were too weak and required almost touching the hall effect for more than a .1V difference in reading. We got our setup mostly done and Payton is going to work on writing code for the LEDs. 

# February 25th, 2026 - PCB Main Board Routing
**Objectives**: Route the Main PCB so we can submit before the first board order round. 

**What Got Done**: Finished routing the PCB. I needed to change some pins on the ESP32, but found a way to duplicate the 8 ADC layouts. I kept the power regulator as far from everything as I could to reduce noise on digital lines like I2C. 

# March 2nd, 2026 - Design Review
**Objectives**: Present our design document and get feedback from our peers and Prof Fliflit.

**What Got Done**: We got mostly positive feedback, but some things we needed to fix. Fliflit told us to add a section about tolerances and to adjust our schedule to be more precise.

# March 5th, 2026 - Breadboard Demo Planning & What Needs to Get Done Before Spring Break
**Objectives**: Plan our our breadboard demo and assign tasks for spring break.

**What Got Done**: We planned out how we would demo and ensured that all our components worked. We then assigned tasks like code that needed to be done and hardware validation. 

# March 5th, 2026 - Putting Together Purchase Order for First PCB assembly
**Objectives**: Get digikey order together for one Chess Board.

**What Got Done**: I used the BOM feature in KiCAD to find all the parts on Digikey. Everything was in stock and priced well so no issues. I also ordered a couple different sample magnets that we could test. The order is supposed to come after spring break. 

# March 9th, 2026 - Breadboard Demo
**Objectives**: Demonstrate piece detection and LED subsystem as well as show we can program the ESP.

**What Got Done**: We were able to deomonstrate all of the subsystems we want and Prof Fliflit was impressed. This is a good demo that, if transfers to our PCB correctly, we are close to having our hardware complete. 

# March 24th, 2026 - First PCB Assembly
**Objectives**: We got our parts in during spring break so we are now able to assemble our first PCB. The goal is to fully assemble one and validate it. 

**What Got Done**: We were able to solder everything on using the stencil and reflow oven for SMD parts. We then hand soldered the through holes. We did not have time to validate today but will come in tomorrow.

# March 25th, 2026 - Main PCB Testing
**Objectives**: Validate the Main PCB hardware.

**What Got Done**: We tested first for shorts and found the usb port we ordered was the wrong package having 6 pins instead of 12. This was shorting our 5V to GND. I removed this and then check again and found no shorts. I then checked each pin of the ADCs, I2C pins, and MCU pins. Everything looked so I powered the regulator and read a 3.29V output which is more than accurate enough. I then bridged the solder jumper and powered the board again. Same 3.29V reading so no other issues. This validates the basic electrical capabilites of our PCB

# March 27th, 2026 - Program Main PCB For The First Time
**Objectives**: We want to program the PCB with the breadboard demo code to show it translated to our PCB.

**What Got Done**: We were able to successfully flash the code after some slight issues. First, we were flashing while the board sat on our stencil which is metalic and caused shorting. Luckily nothing broke. We then tried reading the the ADC but had the wrong I2C pins in the program. We were able to validate our program worked.

We then had a discussion about the physical aspect of our board. Our biggest concern was mounting the hall effect sensors to the bottom of a wooden board. The ideal situation would be to mount them on a PCB or breadboard. To solve this issue we decided we could make each game tile its own PCB that has a sensor mounted on it. We priced this out and for 150 (75 black and 75 white) 1.5" square pcbs it would only be $13 with shipping being more expensive at $45. We decided that this would be our best path forward as we could also 3d print the rest of the enclosure. 

# March 30th, 2026 - Tile PCB Schematic and Routing
**Objectives**: Create and purchase the tile PCBs.

**What Got Done**: I created the schematic for the Tile PCBs which is quite simple. It is only the hall effect sensor, a decoupling capacitor, and pin headers for power/gnd daisy chaining, LEDs, and analog sensor output. We already ordered the through hole hall effect sensors but to mount them in the correct orientation and centered, we can solder them to the top of the through hole pads. We then ordered the PCBs and pin headers for them. 

# April 12th, 2026 - 3D Modeling Tile Supports
**Objectives**: Model the supports for the Tile PCBs

**What Got Done**: I found a [dove tail connected chess board](https://www.thingiverse.com/thing:1269307) online that I modified to have four supports with M2x6mm screw holes. I also had to create 2 other varients with. One with both dove tails cut off for the corner, and one with only one cut off for the edges. The issue we are running into with these is the quantity needed and print time. We need a total of 128 and 25 take 7.5 hours. This means we need over 37.5 hours of print time just for these. The other issue we ran into is that the dove tailes are not tight enough and slide around easily. Our solution to this is to create a walled baseplate that the tile supports will sit in. We chose not to createa a baseplate with supports so that if one tile breaks it is easier to service and repair. We are starting printing.

# April 15th, 2026 - 3D Modeling Baseplates & Getting Screws
**Objectives**: Create the baseplates for the tile supports.

**What Got Done**: For the size of the game board, we need to have 4 prints for the baseplates. We need 2 for the corners in the back, 2 with just one side with walls, and then supports for both the screen and main PCB. We also found [game pieces](https://www.printables.com/model/1552876-simple-set-of-chess-pieces/files) that we modified to have press fit holes for the magnets. When all of these are done we will glue the baseplates together. 

I also went out to find screws. I needed 512 M2x6mm and 8 M3x3mm screws. I went to a local hardware store and they did not have the quantities we needed. So, we went to McMaster-Carr and the screws will come tomorrow. These were failry cheap getting 600 M2 and 50 M3 for $40.

# April 16th, 2026 - Assembly of the Physical Board
**Objectives**: Assemble and validate the first board.

**What Got Done**: To do this we needed to screw all the tile PCBs to the supports and then wire each column to the main PCB. We have been slowly soldering the tile PCBs together over the past week. It took a couple hours to get everything assembled. We had one issue with getting the LEDs to fit because of the wiring of power and sensors. We decided that we could discard the LED subsystem in favor for a UI on the display. This was unfortunate but not a detriment to our high level requirments. 

We then validated the board finding that one of our ADCs was not working. I tried soldering it again, checking for shorts, and replacing it. Nothing works but after using a new one and reworking it a bit we were able to read from it. At ths stage our physical board is done and now Payton and Danny will start implementing their code. 

# April 23rd, 2026 - Mock Demo
**Objectives**: Get feedback on our demonstration and show that one entire board works.

**What Got Done**: We had an issue where we couldn't connect to the illinoisnet wifi. However, Payton was able to connect to his home wifi. We found that the issue was that the board we were using was the second board we assembled. We had never registered this board's MAC address with the university so it could not connect to the wifi. The demo went ok besides that and our TA said if we can get a second board done we are in a great position. After fixing the wifi issue, we were able to connect to our server and play a game between the board and server. 

# April 24th, 2026 - Mock Presentation
**Objectives**: Get feedback on a shortened version of our presentation

**What Got Done**: We got good feedback about using less words and more images. As well as changing our block diagram to be more readable. 

# April 27th, 2026 - Second Board Done
**Objectives**: Get the second board done and validate. 

**What Got Done**: This assembly went easier because we had shorter wires to work with for daisy chaining. Once the board was assembled we flashed it and it worked. No issues with this assembly. 

# April 28th, 2026 - Prep For Final Demo
**Objectives**: Get ready for our final demonstration. 

**What Got Done**: We scripted out a game that will show edge cases like castle, en passant, check mate, and capture. We also want to show off our new AI features like hints and versus AI. We are prepared for demo. 

# April 29th, 2026 - Final Demo
**Objectives**: Present our final demonstration with two working boards. 

**What Got Done**: We were able to demonstrate two working boards playing on seperate networks and worked through our scripted game. We answered all questions asked. 

# April 30th, 2026 - Prep For Final Presentation
**Objectives**: Go over last minute ideas and get ready for presentation.

**What Got Done**: We cut out parts we thought were time wasters and reformated to UIUC ECE slides. We feel prepared and that we will be timely in our presentation.

# May 1st, 2026 - Final Presentation & Demonstration Video
**Objectives**: Present our project.

**What Got Done**: Presented and defended our project and its design. Got added as an honorable mention project.

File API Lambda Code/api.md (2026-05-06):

# ♟️ ESP32 Smart Chessboard API

## Base URL

```
https://j3zvk9adv0.execute-api.us-east-2.amazonaws.com/api/v1
```

---

## Overview

This API manages a single active chess game (`gameId = 1`).

The backend acts as a **state store**, not a chess engine.

### Client Responsibilities

* Detect moves (e.g., `e2e4`)
* Compute **full FEN string**
* Send both move + FEN to the server

### Server Responsibilities

* Store game state
* Track move history
* Synchronize clients

---

## Game Model

### Game Object

```json
{
  "gameId": "1",
  "status": "ACTIVE",
  "fen": "string",
  "turn": "A | B",
  "version": 0,
  "createdAt": 1234567890,
  "lastMoveAt": 1234567890,
  "moveHistory": []
}
```

### Move Entry

```json
{
  "ply": 1,
  "turn": "A",
  "move": "e2e4",
  "at": 1234567890,
  "fen": "full fen string"
}
```

---

## Endpoints

---

### 🔹 Get Current Game State

```http
GET /games/1
```

#### Response

```json
{
  "gameId": "1",
  "status": "ACTIVE",
  "fen": "rnbqkbnr/pppppppp/8/8/4P3/8/PPPP1PPP/RNBQKBNR b KQkq - 0 1",
  "turn": "B",
  "version": 1,
  "lastMoveAt": 1771822779
}
```

---

### 🔹 Get Move History

```http
GET /games/1/moves
```

#### Response

```json
{
  "gameId": "1",
  "version": 1,
  "moves": [
    {
      "ply": 1,
      "turn": "A",
      "move": "e2e4",
      "at": 1771822779,
      "fen": "rnbqkbnr/pppppppp/8/8/4P3/8/PPPP1PPP/RNBQKBNR b KQkq - 0 1"
    }
  ]
}
```

---

### 🔹 Submit Move

```http
POST /games/1/moves
```

#### Request Body

```json
{
  "move": "e2e4",
  "fen": "rnbqkbnr/pppppppp/8/8/4P3/8/PPPP1PPP/RNBQKBNR b KQkq - 0 1",
  "expectedVersion": 0
}
```

#### Required Fields

* `move` → algebraic move string
* `fen` → **full updated FEN**

#### Optional Fields

* `expectedVersion` → prevents conflicting updates

#### Response

```json
{
  "gameId": "1",
  "status": "ACTIVE",
  "fen": "...",
  "turn": "B",
  "version": 1,
  "lastMoveAt": 1771822779,
  "acceptedMove": {
    "ply": 1,
    "turn": "A",
    "move": "e2e4",
    "at": 1771822779,
    "fen": "..."
  }
}
```

---

### 🔹 Reset Game

```http
POST /games/1/reset
```

#### Response

```json
{
  "gameId": "1",
  "status": "ACTIVE",
  "fen": "startpos",
  "turn": "A",
  "version": 0,
  "lastMoveAt": 1771822779,
  "movesCleared": true
}
```

---

## FEN Format

The API expects **full FEN strings**:

```
<board> <turn> <castling> <en passant> <halfmove> <fullmove>
```

### Example

```
rnbqkbnr/pppppppp/8/8/4P3/8/PPPP1PPP/RNBQKBNR b KQkq - 0 1
```

---

## Important Notes

### ⚠️ Backend does NOT:

* Validate moves
* Compute FEN
* Enforce chess rules

### ✅ Backend DOES:

* Store state
* Track moves
* Handle version conflicts

---

## Version Control

To avoid conflicting updates:

* Each move increments `version`
* Client should send `expectedVersion`
* If mismatch → server returns **409 conflict**

---

## Error Responses

### Not Found

```json
{
  "error": {
    "code": "NOT_FOUND",
    "message": "game not found"
  }
}
```

### Missing Fields

```json
{
  "error": {
    "code": "BAD_REQUEST",
    "message": "fen is required"
  }
}
```

### Version Conflict

```json
{
  "error": {
    "code": "VERSION_CONFLICT",
    "message": "state version mismatch"
  },
  "state": { ... }
}
```

---

## Example Usage

### Get Game

```bash
curl https://j3zvk9adv0.execute-api.us-east-2.amazonaws.com/api/v1/games/1
```

### Post Move

```bash
curl -X POST https://j3zvk9adv0.execute-api.us-east-2.amazonaws.com/api/v1/games/1/moves \
  -H "Content-Type: application/json" \
  -d '{
    "move": "e2e4",
    "fen": "rnbqkbnr/pppppppp/8/8/4P3/8/PPPP1PPP/RNBQKBNR b KQkq - 0 1",
    "expectedVersion": 0
  }'
```

---

## Recommended Improvement

Replace `"startpos"` with full FEN:

```
rnbqkbnr/pppppppp/8/8/8/8/PPPPPPPP/RNBQKBNR w KQkq - 0 1
```

This keeps the API consistent and simplifies client logic.

---

## Client Flow Summary

1. Fetch current state
2. Detect move
3. Compute new FEN
4. POST move + FEN
5. Other client syncs via GET

---

## Project Context

This API is designed for a **network-connected physical chessboard** using:

* ESP32
* LED board state rendering
* Sensor-based move detection
* Real-time synchronization between boards

---

## AWS Setup Guide

This section documents how to deploy the backend from scratch in AWS.

### Prerequisites

* AWS account with console and CLI access
* [AWS CLI](https://docs.aws.amazon.com/cli/latest/userguide/install-cliv2.html) installed and configured (`aws configure`)
* Python 3.12 available locally for packaging

---

### Step 1 — Create the DynamoDB Table

1. Open **AWS Console → DynamoDB → Tables → Create table**
2. Configure:
   - **Table name**: `chess-game` (or any name — you will pass it to Lambda as an env var)
   - **Partition key**: `gameId` (String)
   - **Sort key**: none
   - **Billing mode**: On-demand (pay-per-request)
3. Leave all other settings as default and click **Create table**.

The table schema is managed entirely by the Lambda code (`ensure_single_game()`). No additional index or attribute setup is needed.

---

### Step 2 — Create the Stockfish Lambda Layer

The `/hint` and AI move endpoints require Stockfish compiled for Amazon Linux 2 (the Lambda runtime environment). A pre-built binary is available from the community:

1. Download the Amazon Linux 2 build of Stockfish:
   ```bash
   # Example — check for the latest release at https://github.com/official-stockfish/Stockfish
   wget https://github.com/official-stockfish/Stockfish/releases/download/sf_16/stockfish-ubuntu-x86-64.tar
   ```
2. Create the required directory structure and zip it:
   ```bash
   mkdir -p layer/bin
   cp stockfish layer/bin/stockfish
   chmod +x layer/bin/stockfish
   cd layer && zip -r ../stockfish-layer.zip bin/
   ```
3. In the AWS Console, go to **Lambda → Layers → Create layer**:
   - **Name**: `stockfish`
   - **Upload**: `stockfish-layer.zip`
   - **Compatible runtimes**: Python 3.12
4. Note the **Layer ARN** — you will attach it to the Lambda function in Step 4.

The code expects the binary at `/opt/bin/stockfish` (the `/opt/` prefix is how Lambda exposes layer contents).

---

### Step 3 — Create the Lambda Function

1. Go to **Lambda → Functions → Create function**
2. Configure:
   - **Author from scratch**
   - **Function name**: `chess-api`
   - **Runtime**: Python 3.12
   - **Architecture**: x86_64
3. Click **Create function**.

#### Deploy the code

Package and upload `api.py`:

```bash
cd "API Lambda Code"
zip function.zip api.py
aws lambda update-function-code \
  --function-name chess-api \
  --zip-file fileb://function.zip
```

#### Set the handler

In **Configuration → General configuration → Edit**:
- **Handler**: `api.lambda_handler`

#### Set environment variables

In **Configuration → Environment variables → Edit**, add:

| Key | Value |
|---|---|
| `TABLE_NAME` | `chess-game` (your DynamoDB table name) |

#### Attach the Stockfish layer

In **Configuration → Layers → Add a layer**:
- Select **Custom layers**, choose `stockfish`, and select the latest version.

#### Set memory and timeout

In **Configuration → General configuration → Edit**:
- **Memory**: 512 MB (Stockfish needs headroom; the code caps its hash table at 16 MB)
- **Timeout**: 10 seconds (Stockfish at depth 12 can take a few seconds)

---

### Step 4 — IAM Permissions

The Lambda execution role needs DynamoDB access. Attach the following policy to the role (found under **Configuration → Permissions → Execution role**):

```json
{
  "Version": "2012-10-17",
  "Statement": [
    {
      "Effect": "Allow",
      "Action": [
        "dynamodb:GetItem",
        "dynamodb:PutItem",
        "dynamodb:UpdateItem",
        "dynamodb:DeleteItem"
      ],
      "Resource": "arn:aws:dynamodb:us-east-2:YOUR_ACCOUNT_ID:table/chess-game"
    }
  ]
}
```

Replace `YOUR_ACCOUNT_ID` and `chess-game` with your actual values. The AWS managed policy `AmazonDynamoDBFullAccess` also works for development but is overly broad for production.

---

### Step 5 — Create the API Gateway

The Lambda handler is written for **API Gateway HTTP API (v2)** — it reads `event["requestContext"]["http"]["method"]` and `event["requestContext"]["http"]["path"]`.

1. Go to **API Gateway → Create API → HTTP API → Build**
2. Under **Integrations**, click **Add integration**:
   - **Integration type**: Lambda
   - **Lambda function**: `chess-api`
3. **API name**: `chess-api`
4. Click **Next** through routes and stages — the Lambda function handles all routing internally, so use a catch-all route:
   - **Method**: `ANY`
   - **Resource path**: `/{proxy+}`
5. **Stage name**: `api` (this becomes the first path segment)
6. Click **Create**.

After creation, the console shows your **Invoke URL** in the format:
```
https://<id>.execute-api.<region>.amazonaws.com/api
```

The full base URL used by the firmware and this document is:
```
https://<id>.execute-api.<region>.amazonaws.com/api/v1
```

Update `BASE_URL` in `ChessBoard/api_connect.cpp` if you redeploy to a new endpoint.

---

### Step 6 — Verify the Deployment

```bash
# Should return the initial game state (creates the game record on first call)
curl https://<your-invoke-url>/api/v1/games/1

# Reset to a clean game
curl -X POST https://<your-invoke-url>/api/v1/games/1/reset \
  -H "Content-Type: application/json" \
  -d '{"boardId": "test-board-1", "timerMode": "none"}'

# Submit a move
curl -X POST https://<your-invoke-url>/api/v1/games/1/moves \
  -H "Content-Type: application/json" \
  -d '{
    "move": "e2e4",
    "fen": "rnbqkbnr/pppppppp/8/8/4P3/8/PPPP1PPP/RNBQKBNR b KQkq - 0 1",
    "boardId": "test-board-1",
    "expectedVersion": 0
  }'
```

---

### Architecture Summary

```
ESP32-S3 Boards (HTTPS)
        │
        ▼
API Gateway HTTP API  (ANY /{proxy+})
        │
        ▼
Lambda  chess-api  (Python 3.12, 512 MB, 10 s timeout)
  │  └── Layer: stockfish  (/opt/bin/stockfish)
  │     Env:   TABLE_NAME=chess-game
        │
        ▼
DynamoDB  chess-game  (partition key: gameId)
```

---

### Redeployment Checklist

| Step | Command / Action |
|---|---|
| Update Lambda code | `zip function.zip api.py` then `aws lambda update-function-code ...` |
| Update env vars | AWS Console → Lambda → Configuration → Environment variables |
| Update Stockfish layer | Upload new layer version, update Lambda to point to it |
| Change base URL on boards | Update `BASE_URL` in `ChessBoard/api_connect.cpp` and re-flash |

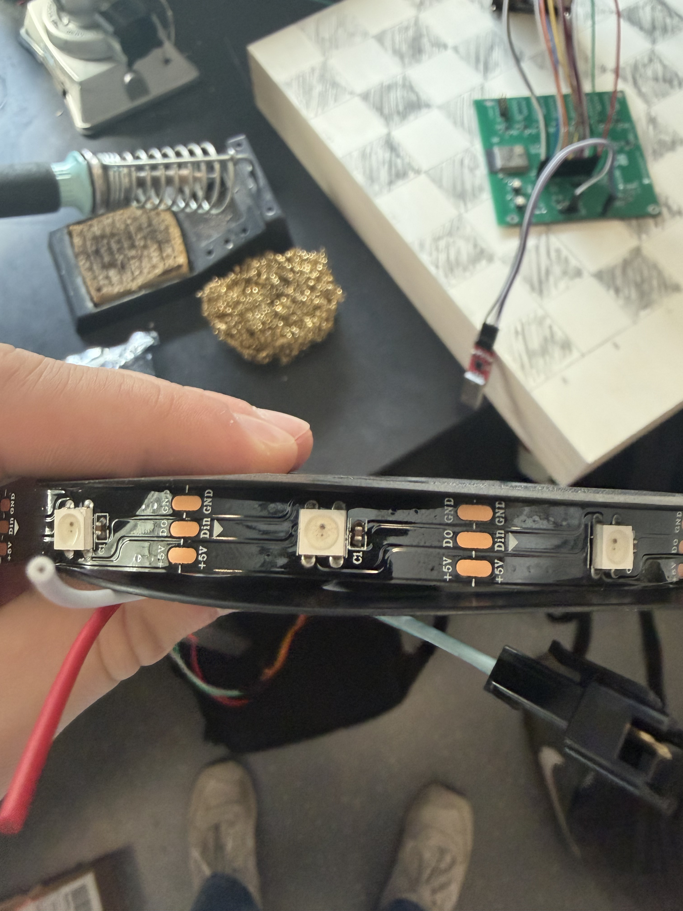
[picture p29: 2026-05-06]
notebooks/Quinn/LED_Strip.jpeg

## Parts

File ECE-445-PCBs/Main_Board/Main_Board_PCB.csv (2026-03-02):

Reference | Qty | Value | DNP | Exclude from BOM | Exclude from Board | Footprint | Datasheet
C1,C2,C11,C12,C13,C16,C17,C18,C21,C22,C23,C26,C27,C28,C31,C32,C33,C36,C37,C38,C41,C42,C43,C46,C47,C48 | 26 | 1uF |  |  |  | Capacitor_SMD:C_0603_1608Metric | ~
C3 | 1 | 4.7uF |  |  |  | Capacitor_SMD:C_0603_1608Metric | ~
C4,C5,C7,C9,C14,C19,C24,C29,C34,C39,C44 | 11 | 10uF |  |  |  | Capacitor_SMD:C_0603_1608Metric | ~
C6 | 1 | 22uF |  |  |  | Capacitor_SMD:C_0603_1608Metric | ~
C8,C10,C15,C20,C25,C30,C35,C40,C45 | 9 | 0.1uF |  |  |  | Capacitor_SMD:C_0603_1608Metric | ~
D1,D2 | 2 | RED LED |  |  |  | LED_SMD:LED_0603_1608Metric | ~
H1,H2,H3,H4 | 4 | MountingHole_Pad |  | Excluded from BOM |  | MountingHole:MountingHole_3.2mm_M3_DIN965_Pad | ~
J1 | 1 | Conn_01x14_Pin |  |  |  | Connector_PinHeader_2.54mm:PinHeader_1x14_P2.54mm_Vertical | ~
J2,J3,J5,J6 | 4 | Conn_01x02_Pin |  |  |  | Connector_PinHeader_2.54mm:PinHeader_1x02_P2.54mm_Vertical | ~
J4 | 1 | USB_C_Receptacle_USB2.0_16P |  |  |  | Connector_USB:USB_C_Receptacle_G-Switch_GT-USB-7010ASV | https://www.usb.org/sites/default/files/documents/usb_type-c.zip
J7 | 1 | Conn_01x05_Pin |  |  |  | Connector_PinHeader_2.54mm:PinHeader_1x05_P2.54mm_Vertical | ~
J8,J9,J10,J11,J12,J13,J14,J15 | 8 | Conn_02x05_Odd_Even |  |  |  | Connector_Amphenol:AMPHENOL_67997-410HLF | ~
J16 | 1 | Conn_01x03_Pin |  |  |  | Connector_PinHeader_2.54mm:PinHeader_1x03_P2.54mm_Vertical | ~
JP1 | 1 | SolderJumper_3_Open |  | Excluded from BOM |  | Jumper:SolderJumper-3_P1.3mm_Open_Pad1.0x1.5mm | ~
JP2 | 1 | SolderJumper_2_Open |  | Excluded from BOM |  | Jumper:SolderJumper-2_P1.3mm_Open_Pad1.0x1.5mm | ~
L1 | 1 | 2.2uH |  |  |  | Inductor_SMD:L_Coilcraft_1008HQ_2520Metric | ~
Q1,Q2 | 2 | SS8050 |  |  |  | Package_TO_SOT_SMD:SOT-23 | http://www.secosgmbh.com/datasheet/products/SSMPTransistor/SOT-23/SS8050.pdf
R1,R4,R15,R34,R43 | 5 | 100k |  |  |  | Resistor_SMD:R_0603_1608Metric | ~
R2,R3,R5,R6,R20,R21,R22,R23,R24,R25,R26,R27 | 12 | 4.7k |  |  |  | Resistor_SMD:R_0603_1608Metric | ~
R7,R8,R11,R12 | 4 | 10k |  |  |  | Resistor_SMD:R_0603_1608Metric | ~
R9,R10 | 2 | 5.1k |  |  |  | Resistor_SMD:R_0603_1608Metric | ~
R13 | 1 | 475k |  |  |  | Resistor_SMD:R_0603_1608Metric | ~
R14 | 1 | 450k |  |  |  | Resistor_SMD:R_0603_1608Metric | ~
R16 | 1 | 1k |  |  |  | Resistor_SMD:R_0603_1608Metric | ~
R17,R18 | 2 | 470 |  |  |  | Resistor_SMD:R_0603_1608Metric | ~
R19 | 1 | 1k | DNP |  |  | Resistor_SMD:R_0603_1608Metric | ~
R28 | 1 | 0 |  |  |  | Resistor_SMD:R_0603_1608Metric | ~
R29,R31,R33,R35,R36,R37,R38,R40,R42 | 9 | R_US | DNP |  |  | Resistor_SMD:R_0603_1608Metric | ~
R30,R39 | 2 | 11k |  |  |  | Resistor_SMD:R_0603_1608Metric | ~
R32,R41 | 2 | 33k |  |  |  | Resistor_SMD:R_0603_1608Metric | ~
SW1,SW2 | 2 | SW_Push |  |  |  | Button_Switch_THT:SW_TH_Tactile_Omron_B3F-100x | ~
U1 | 1 | TLV62569DDC |  |  |  | Package_TO_SOT_SMD:SOT-23-6 | http://www.ti.com/lit/ds/symlink/tlv62569.pdf
U2 | 1 | ESP32-S3-WROOM-1 |  |  |  | RF_Module:ESP32-S3-WROOM-1 | https://www.espressif.com/sites/default/files/documentation/esp32-s3-wroom-1_wroom-1u_datasheet_en.pdf
U3,U4,U5,U6,U7,U8,U9,U10 | 8 | ADS7128IRTER |  |  |  | Package_DFN_QFN:WQFN16_RTE_TEX-M | https://www.ti.com/lit/gpn/ads7128

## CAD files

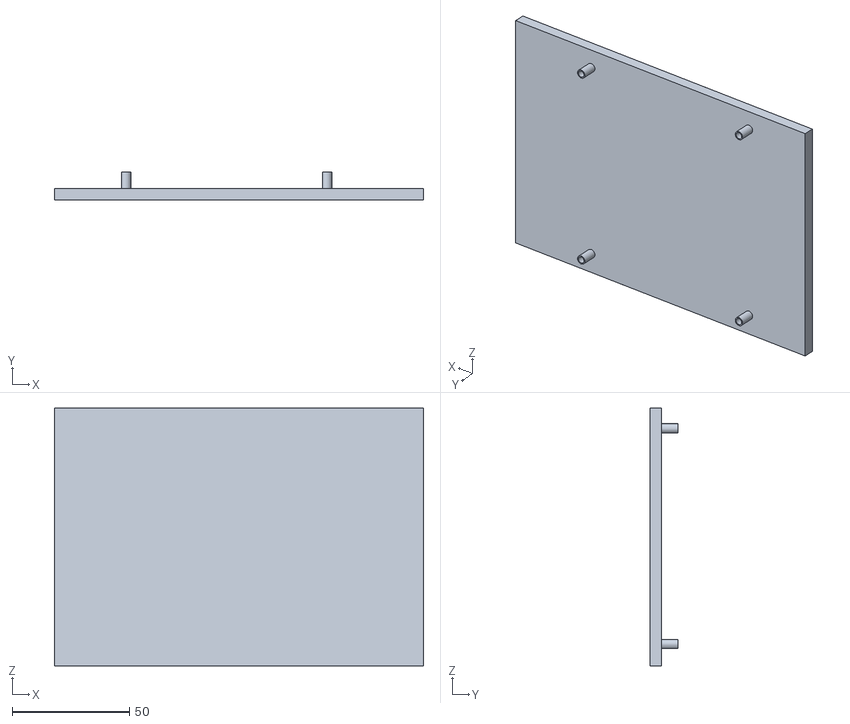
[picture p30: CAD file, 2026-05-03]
Enclosure/STL_Files/MainBoard_Support_V2.stl
157.4 x 12.0 x 110.0

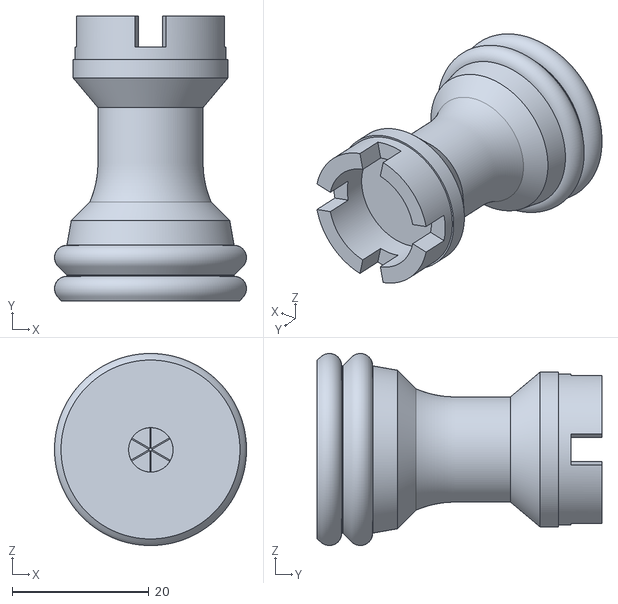
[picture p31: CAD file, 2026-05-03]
Enclosure/STL_Files/Rook_Piece_V1.stl
28.1 x 41.7 x 28.1

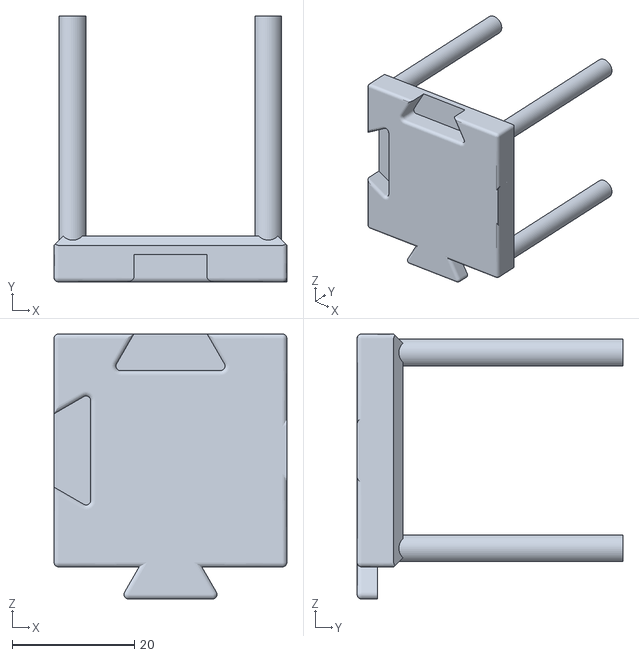
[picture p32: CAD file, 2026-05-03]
Enclosure/STL_Files/One_Peg_support_V1.stl
38.1 x 43.5 x 43.4

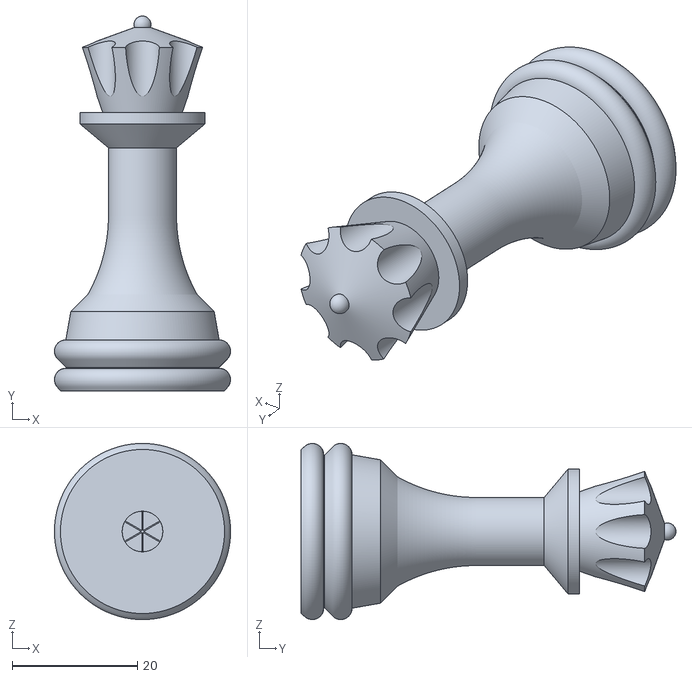
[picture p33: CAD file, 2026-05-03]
Enclosure/STL_Files/Queen_Piece_V2.stl
28.2 x 60.0 x 28.2

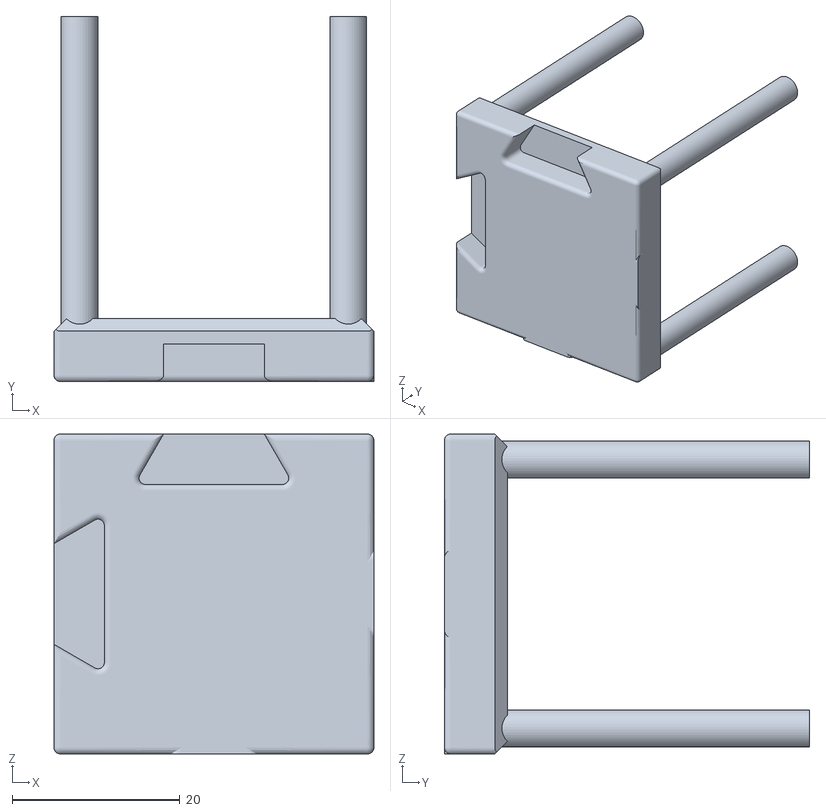
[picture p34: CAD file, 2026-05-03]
Enclosure/STL_Files/Cap_support_v1.stl
38.1 x 43.5 x 38.1

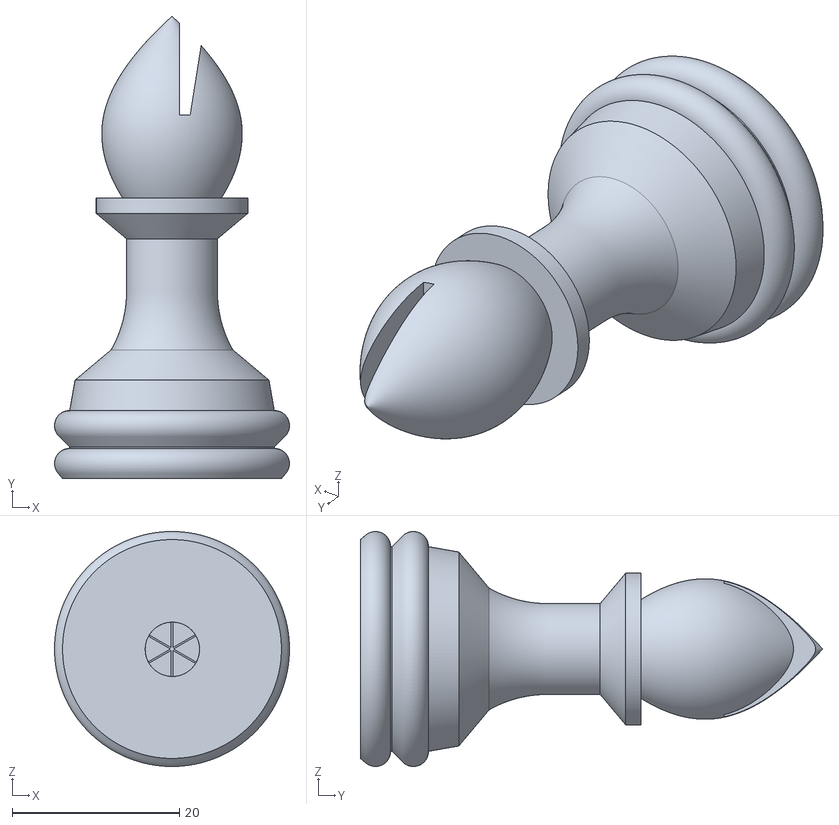
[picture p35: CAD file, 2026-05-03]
Enclosure/STL_Files/Bishop_Piece_V1.stl
28.1 x 55.3 x 28.1

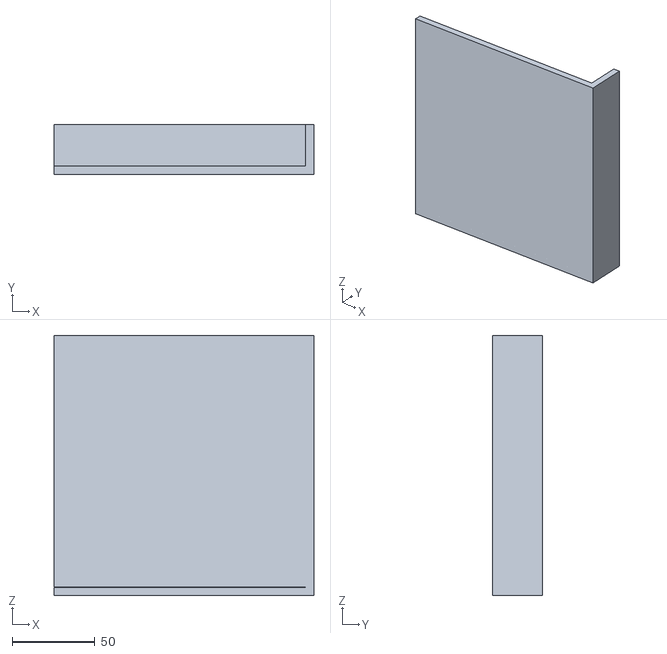
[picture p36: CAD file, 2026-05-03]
Enclosure/STL_Files/baseplate_corner_chess_V1.stl
157.4 x 30.0 x 157.4

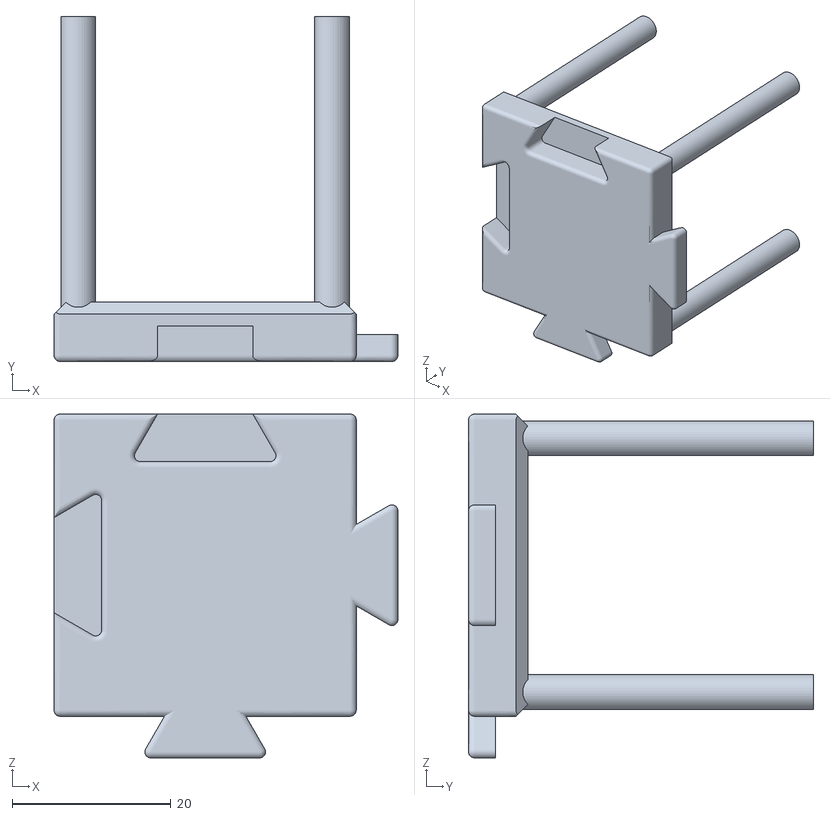
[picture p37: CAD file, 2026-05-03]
Enclosure/STL_Files/Tile_Support_V1.stl
43.3 x 43.5 x 43.4

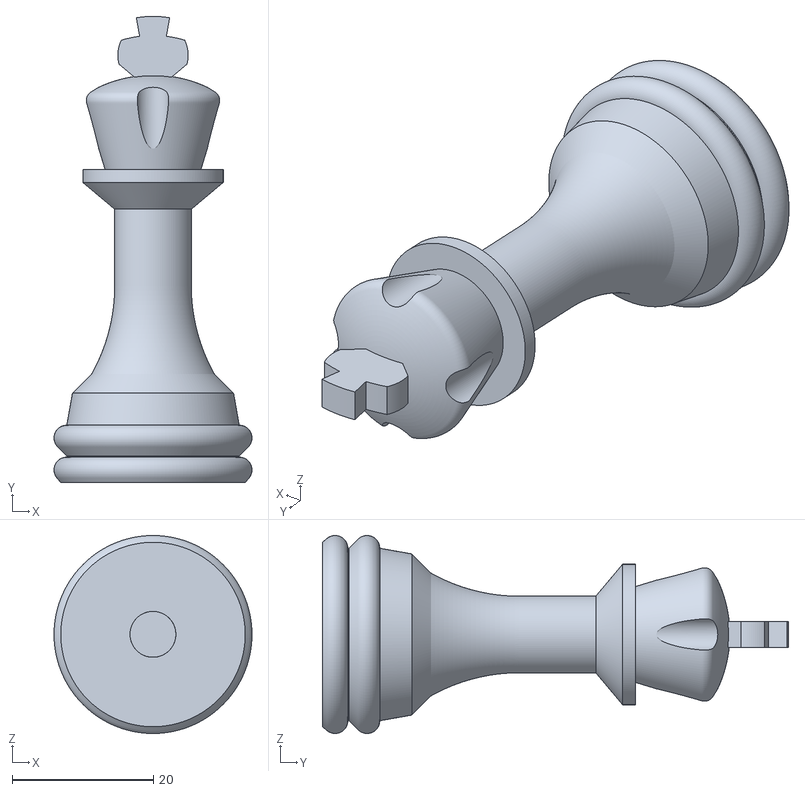
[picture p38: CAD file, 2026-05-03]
Enclosure/STL_Files/King_Piece_V1.stl
28.0 x 66.0 x 28.0

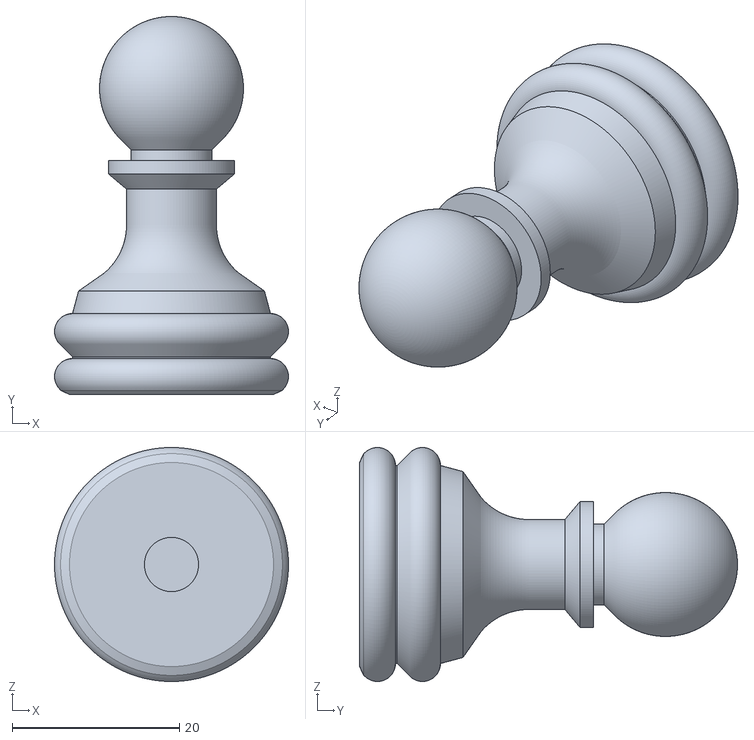
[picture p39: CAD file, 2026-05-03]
Enclosure/STL_Files/Pawn_Piece_V1.stl
28.0 x 45.3 x 28.0

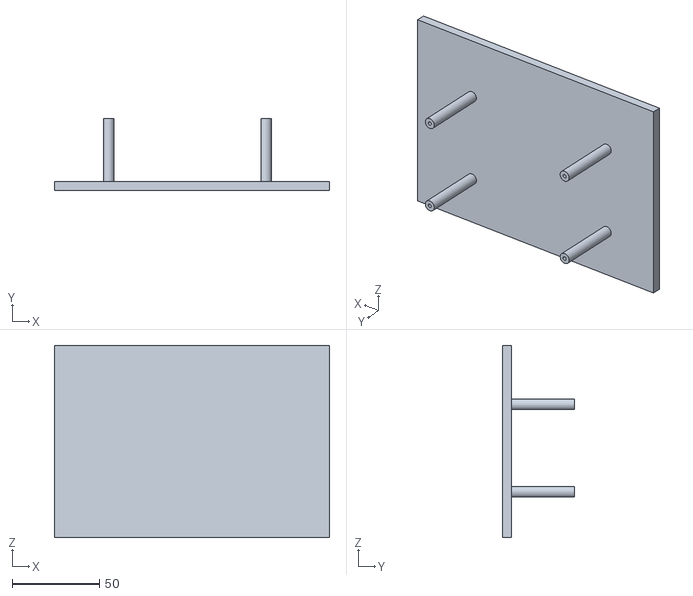
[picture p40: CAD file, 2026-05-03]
Enclosure/STL_Files/Display_support_V1.stl
157.4 x 41.0 x 110.0

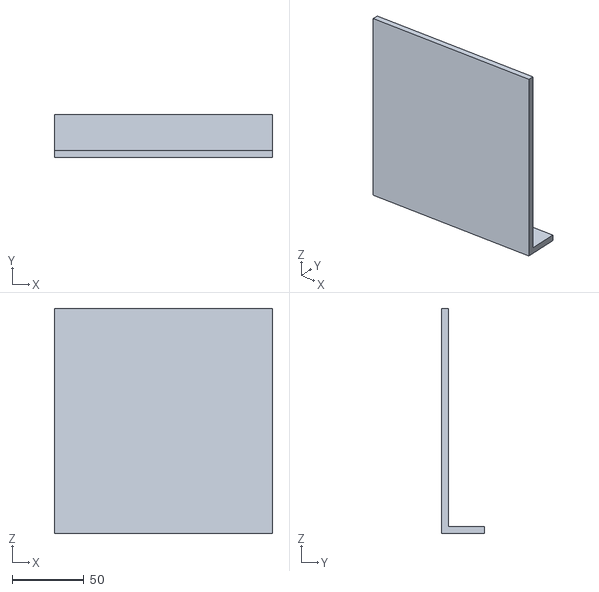
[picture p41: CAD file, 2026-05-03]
Enclosure/STL_Files/Edge_support_base.stl
152.4 x 30.0 x 157.4

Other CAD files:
Enclosure/Fusion_Files/Cap_support_V1.f3d
Enclosure/Fusion_Files/Display_support_V1.f3d
Enclosure/Fusion_Files/Edge_support_base_V1.f3d
Enclosure/Fusion_Files/MainBoard_Support_V1.f3d
Enclosure/Fusion_Files/One_Peg_support_V1.f3d
Enclosure/Fusion_Files/Tile_Support_V1.f3d
Enclosure/Fusion_Files/baseplate_corner_chess_V1.f3d

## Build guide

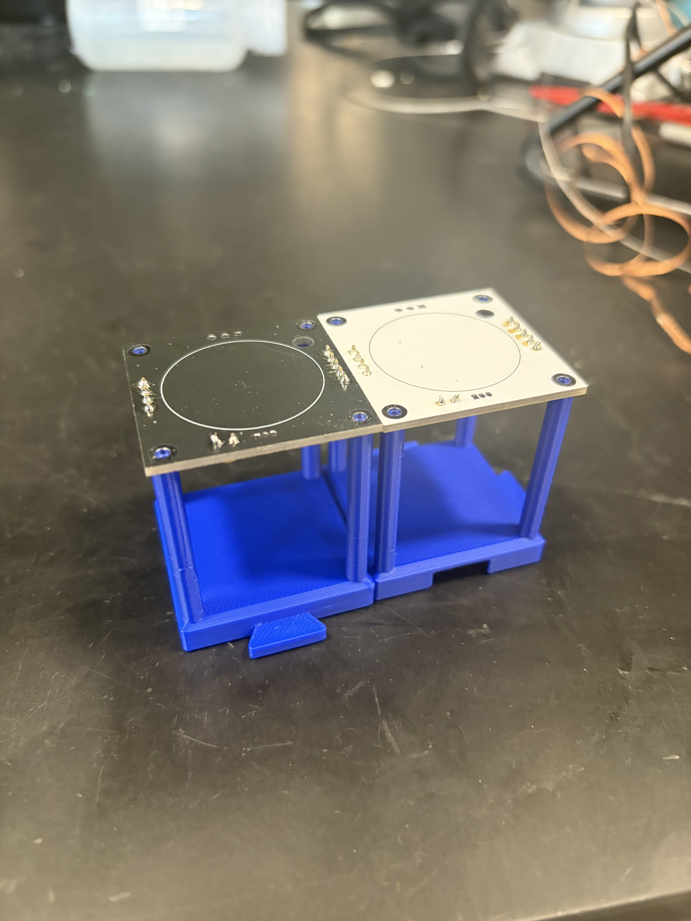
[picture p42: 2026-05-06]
notebooks/Quinn/TilePCB_assembly.jpeg

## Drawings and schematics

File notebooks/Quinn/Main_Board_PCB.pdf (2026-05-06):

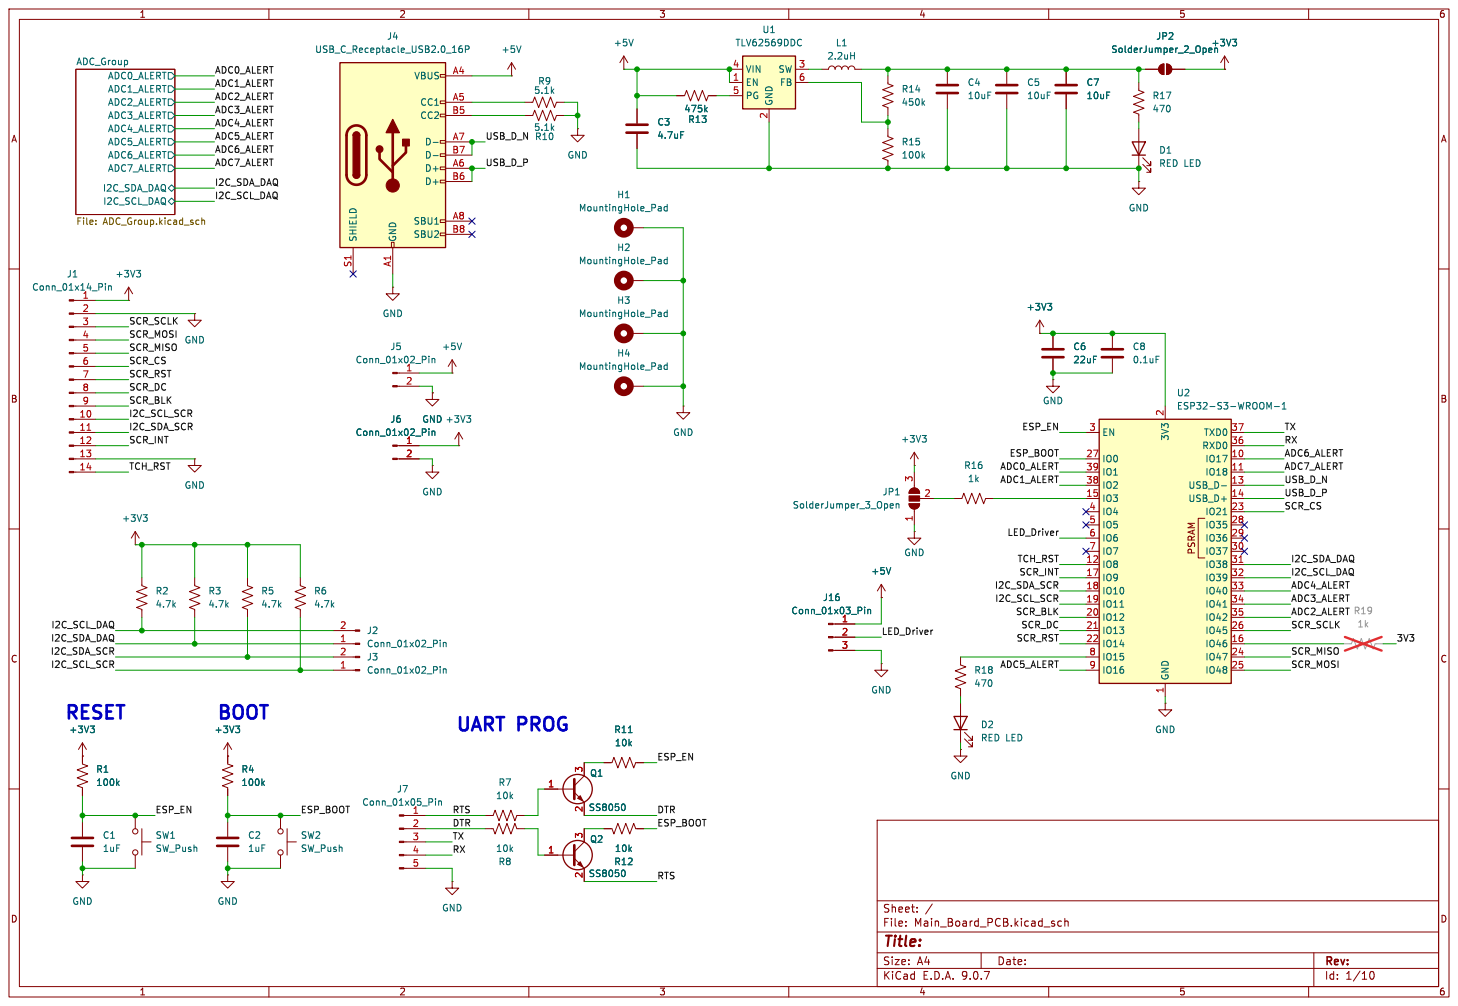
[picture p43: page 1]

Id: 1/10 Title: File: Main_Board_PCB.kicad_sch Sheet: /

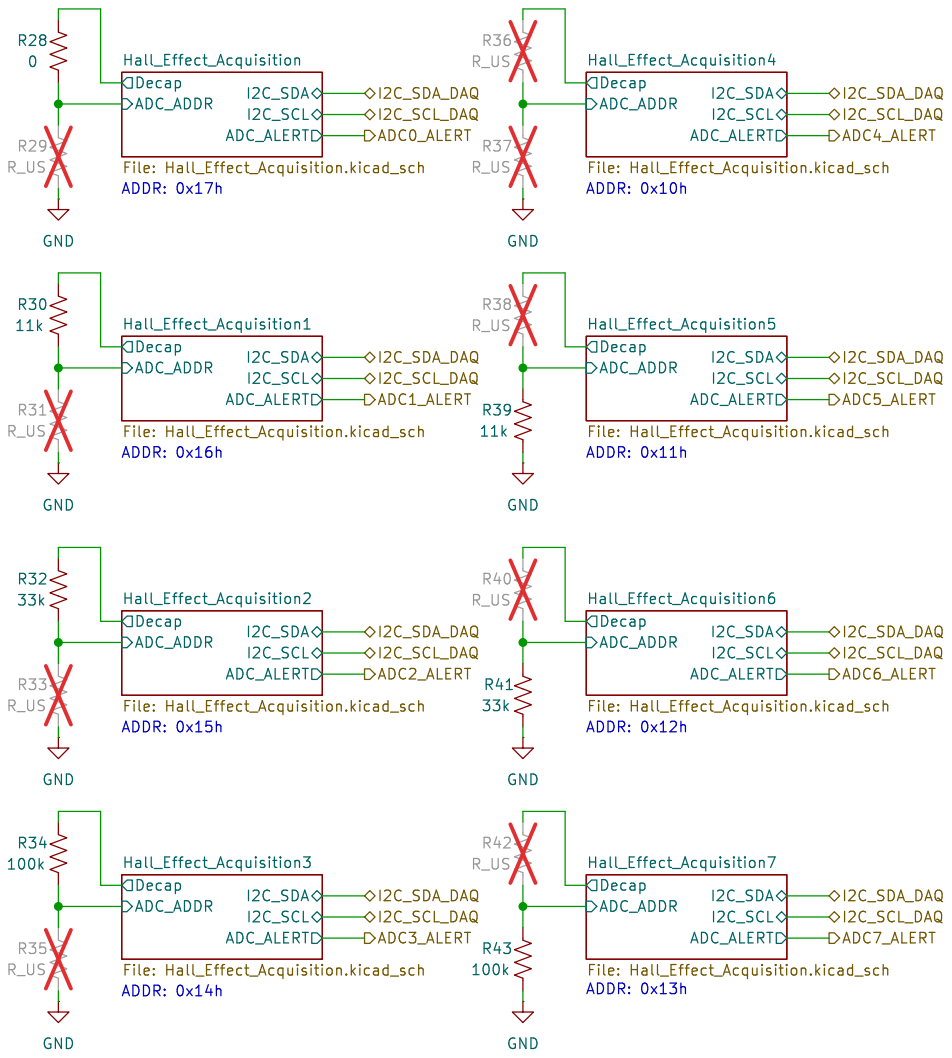
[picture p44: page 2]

Id: 10/10 Title: File: ADC_Group.kicad_sch Sheet: /ADC_Group/

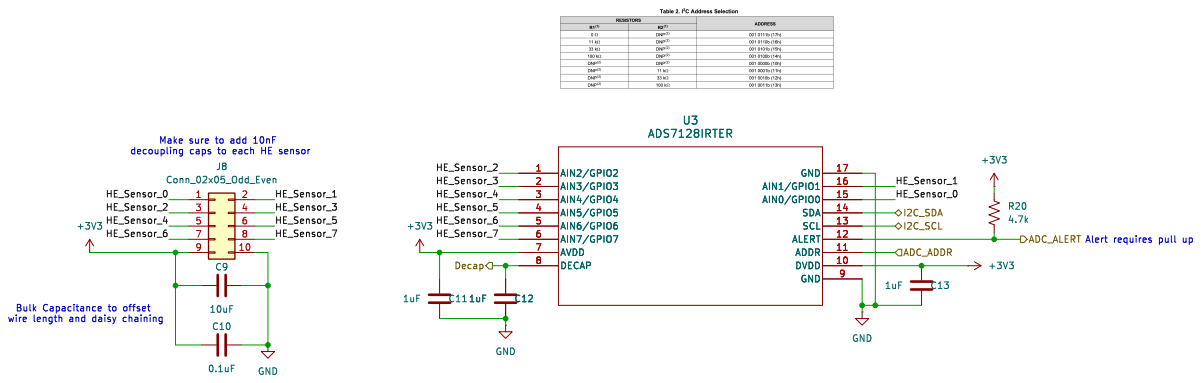
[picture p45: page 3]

Id: 2/10 Title: File: Hall_Effect_Acquisition.kicad_sch Sheet: /ADC_Group/Hall_Effect_Acquisition/ R20

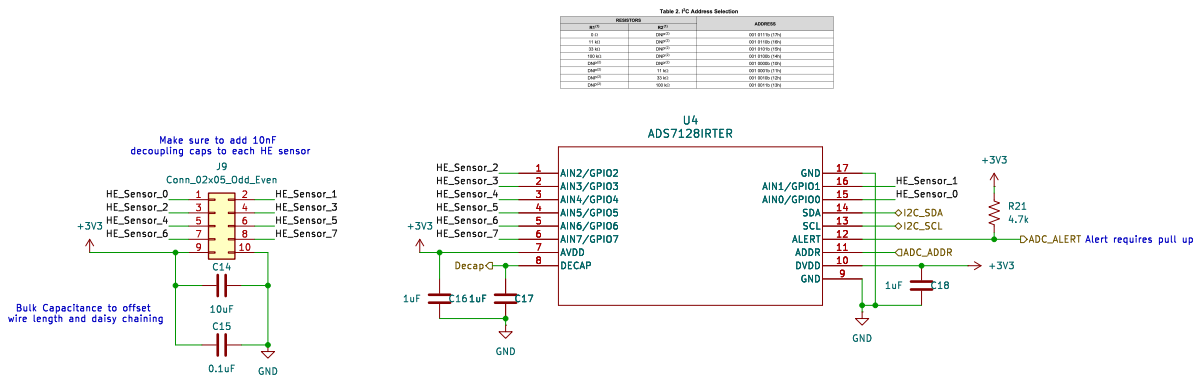
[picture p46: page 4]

Id: 3/10 Title: File: Hall_Effect_Acquisition.kicad_sch Sheet: /ADC_Group/Hall_Effect_Acquisition1/

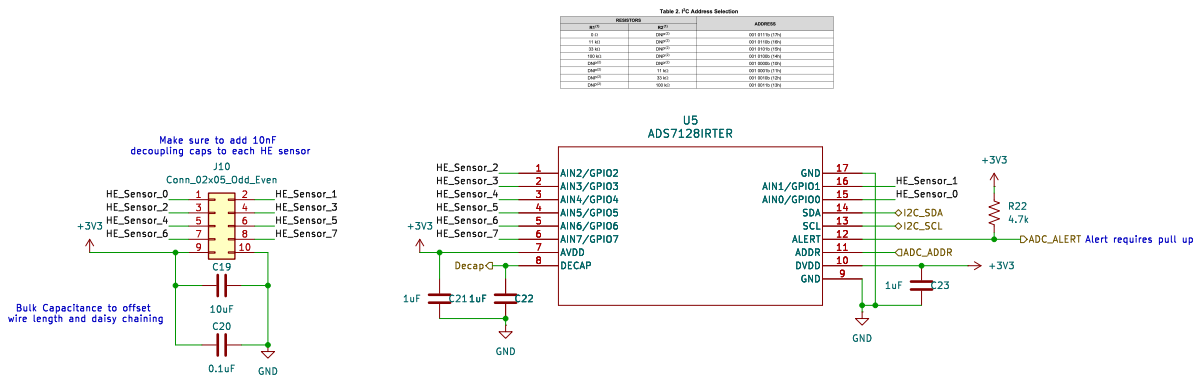
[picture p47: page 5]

Id: 4/10 Title: File: Hall_Effect_Acquisition.kicad_sch Sheet: /ADC_Group/Hall_Effect_Acquisition2/ R22

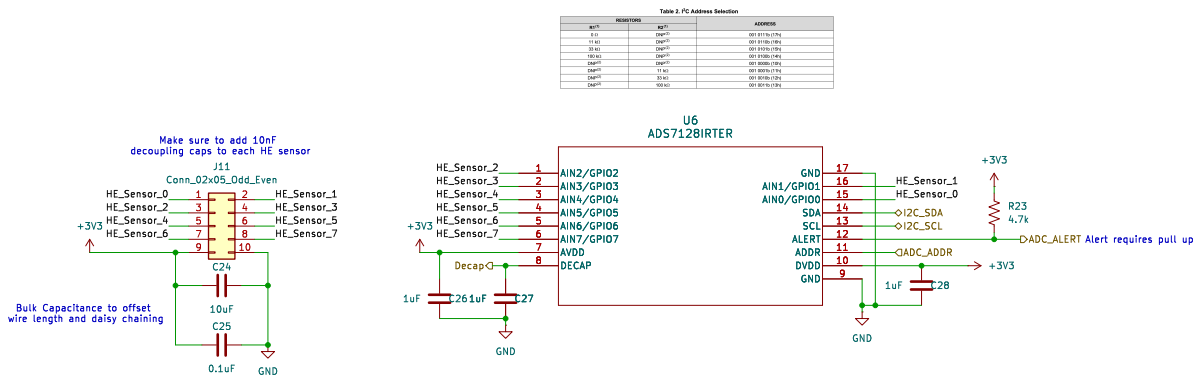
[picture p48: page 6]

Id: 5/10 Title: File: Hall_Effect_Acquisition.kicad_sch Sheet: /ADC_Group/Hall_Effect_Acquisition3/

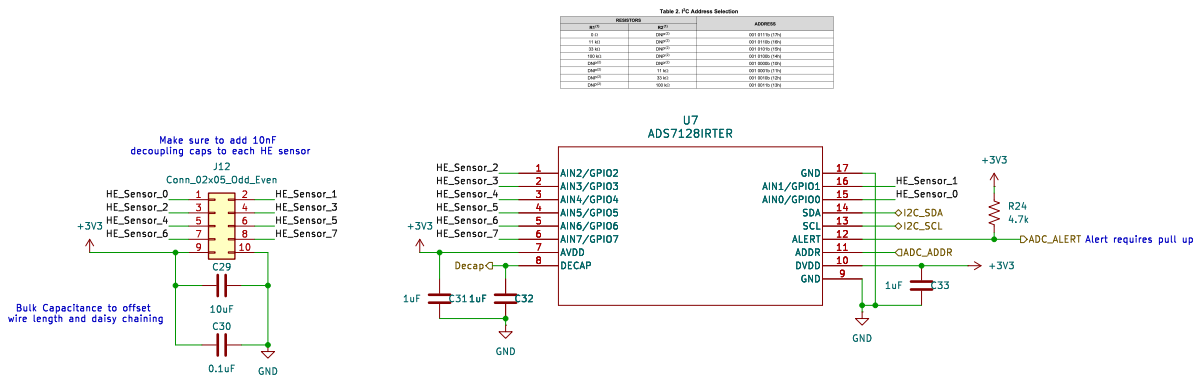
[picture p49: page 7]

Id: 6/10 Title: File: Hall_Effect_Acquisition.kicad_sch Sheet: /ADC_Group/Hall_Effect_Acquisition4/ R24

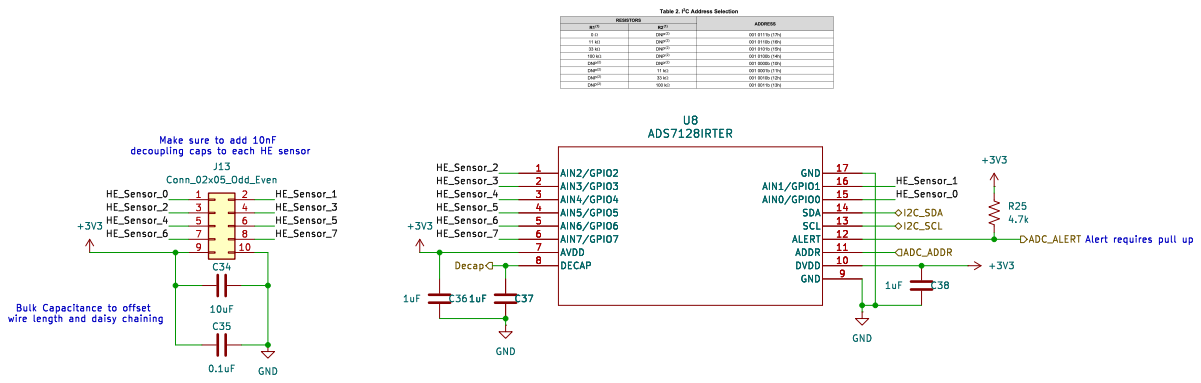
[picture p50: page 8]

Id: 7/10 Title: File: Hall_Effect_Acquisition.kicad_sch Sheet: /ADC_Group/Hall_Effect_Acquisition5/

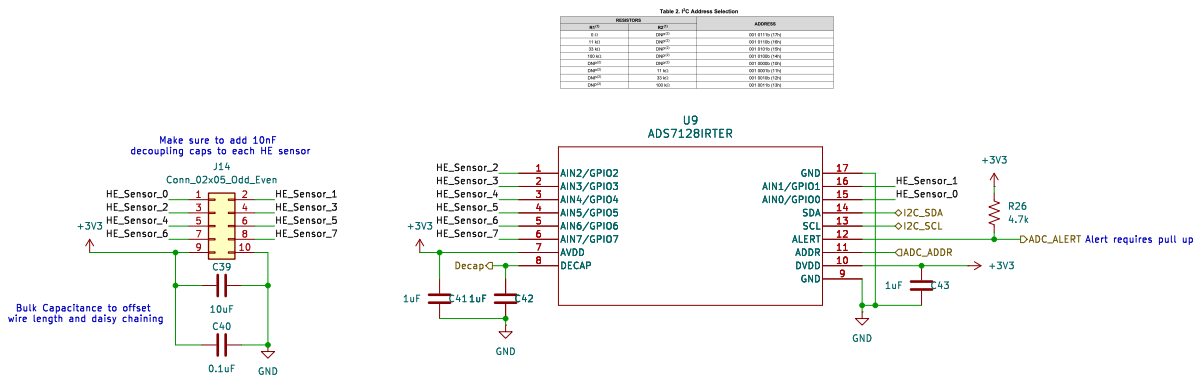
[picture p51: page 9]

Id: 8/10 Title: File: Hall_Effect_Acquisition.kicad_sch Sheet: /ADC_Group/Hall_Effect_Acquisition6/ R26

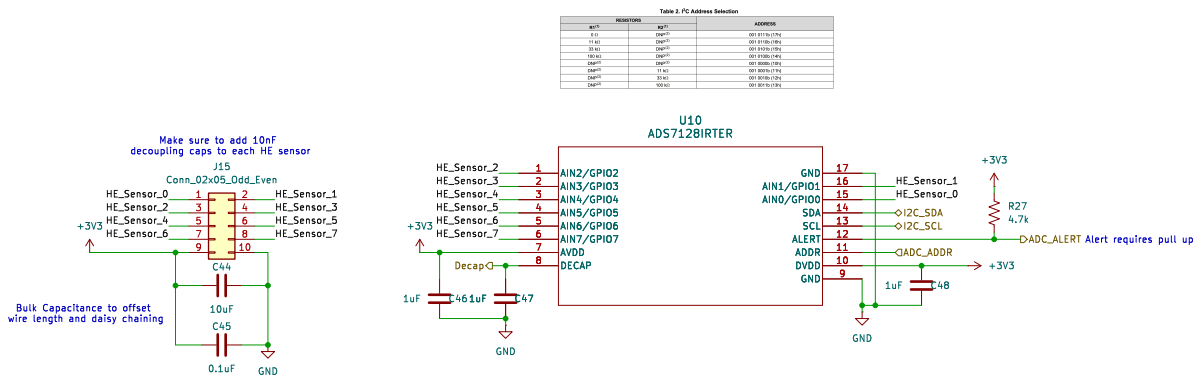
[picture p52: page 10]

Id: 9/10 Title: File: Hall_Effect_Acquisition.kicad_sch Sheet: /ADC_Group/Hall_Effect_Acquisition7/

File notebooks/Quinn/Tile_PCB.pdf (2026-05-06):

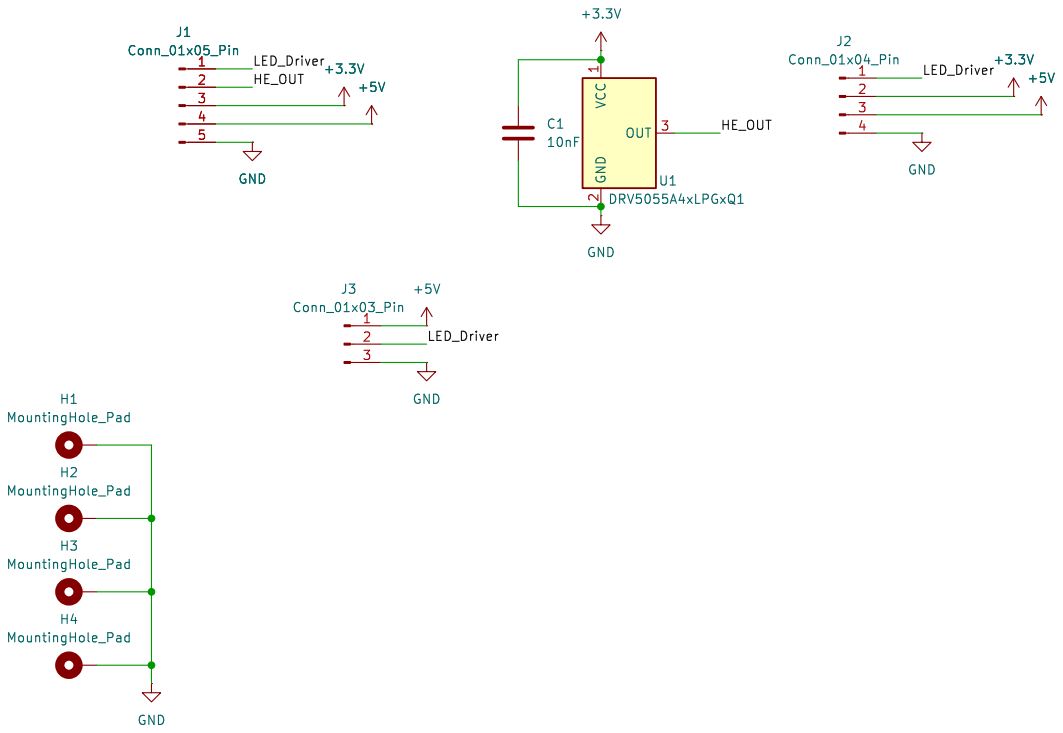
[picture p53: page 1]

Id: 1/1 Title: File: Tile_PCB.kicad_sch Sheet: /

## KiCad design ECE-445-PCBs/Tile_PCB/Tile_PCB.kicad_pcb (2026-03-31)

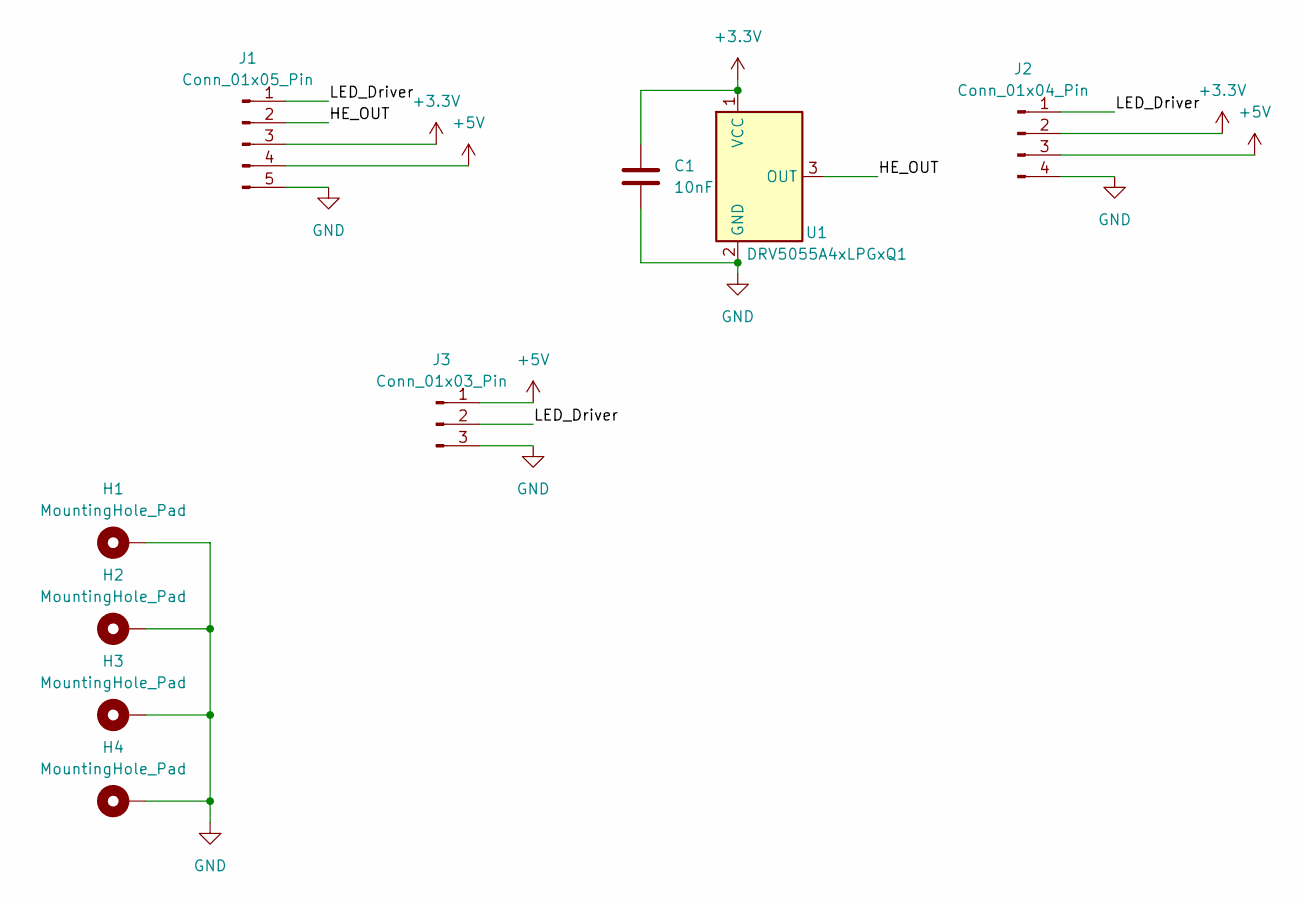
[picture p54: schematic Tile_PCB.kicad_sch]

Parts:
C1: 10nF; CAP_C320C_MOLDED RADIAL_KEM
H1, H2, H3, H4: MountingHole_Pad; MountingHole_2.2mm_M2_Pad
J1: Conn_01x05_Pin; PinHeader_1x05_P2.54mm_Vertical
J2: Conn_01x04_Pin; PinHeader_1x04_P2.54mm_Vertical
J3: Conn_01x03_Pin; PinHeader_1x03_P2.54mm_Vertical
U1: DRV5055A4xLPGxQ1; TO-92_Inline

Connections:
+3.3V: C1.1, J1.3, J2.2, U1.1 (VCC)
+5V: J1.4, J2.3, J3.1
/HE_OUT: J1.2, U1.3 (OUT)
/LED_Driver: J1.1, J2.1, J3.2
GND: C1.2, H1.1, H2.1, H3.1, H4.1, J1.5, J2.4, J3.3, U1.2 (GND)

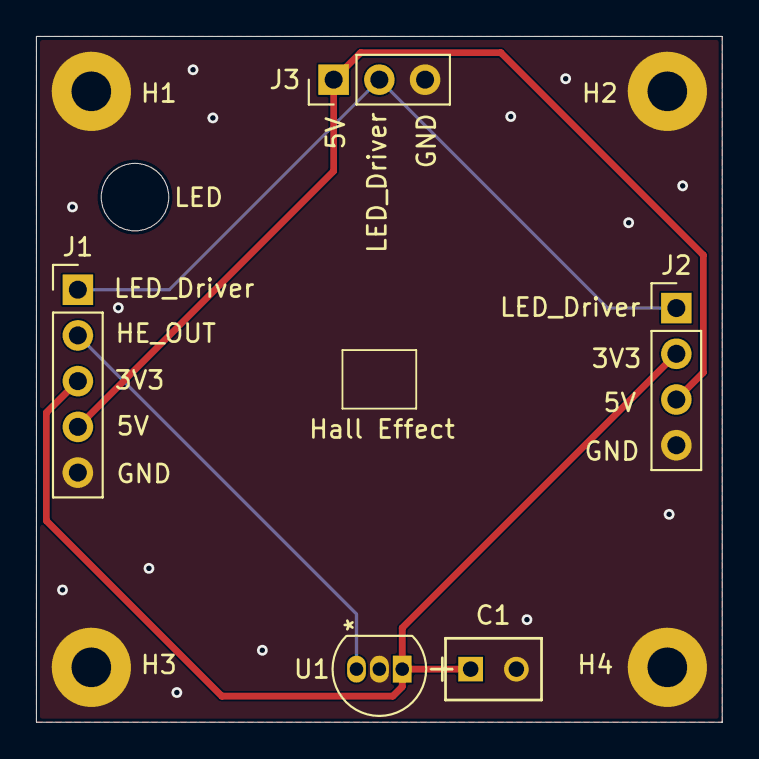
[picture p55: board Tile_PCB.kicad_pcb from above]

Board: 2 copper layers, 38.1 x 38.1 mm, 9 parts (0 on the bottom side), 5 nets.

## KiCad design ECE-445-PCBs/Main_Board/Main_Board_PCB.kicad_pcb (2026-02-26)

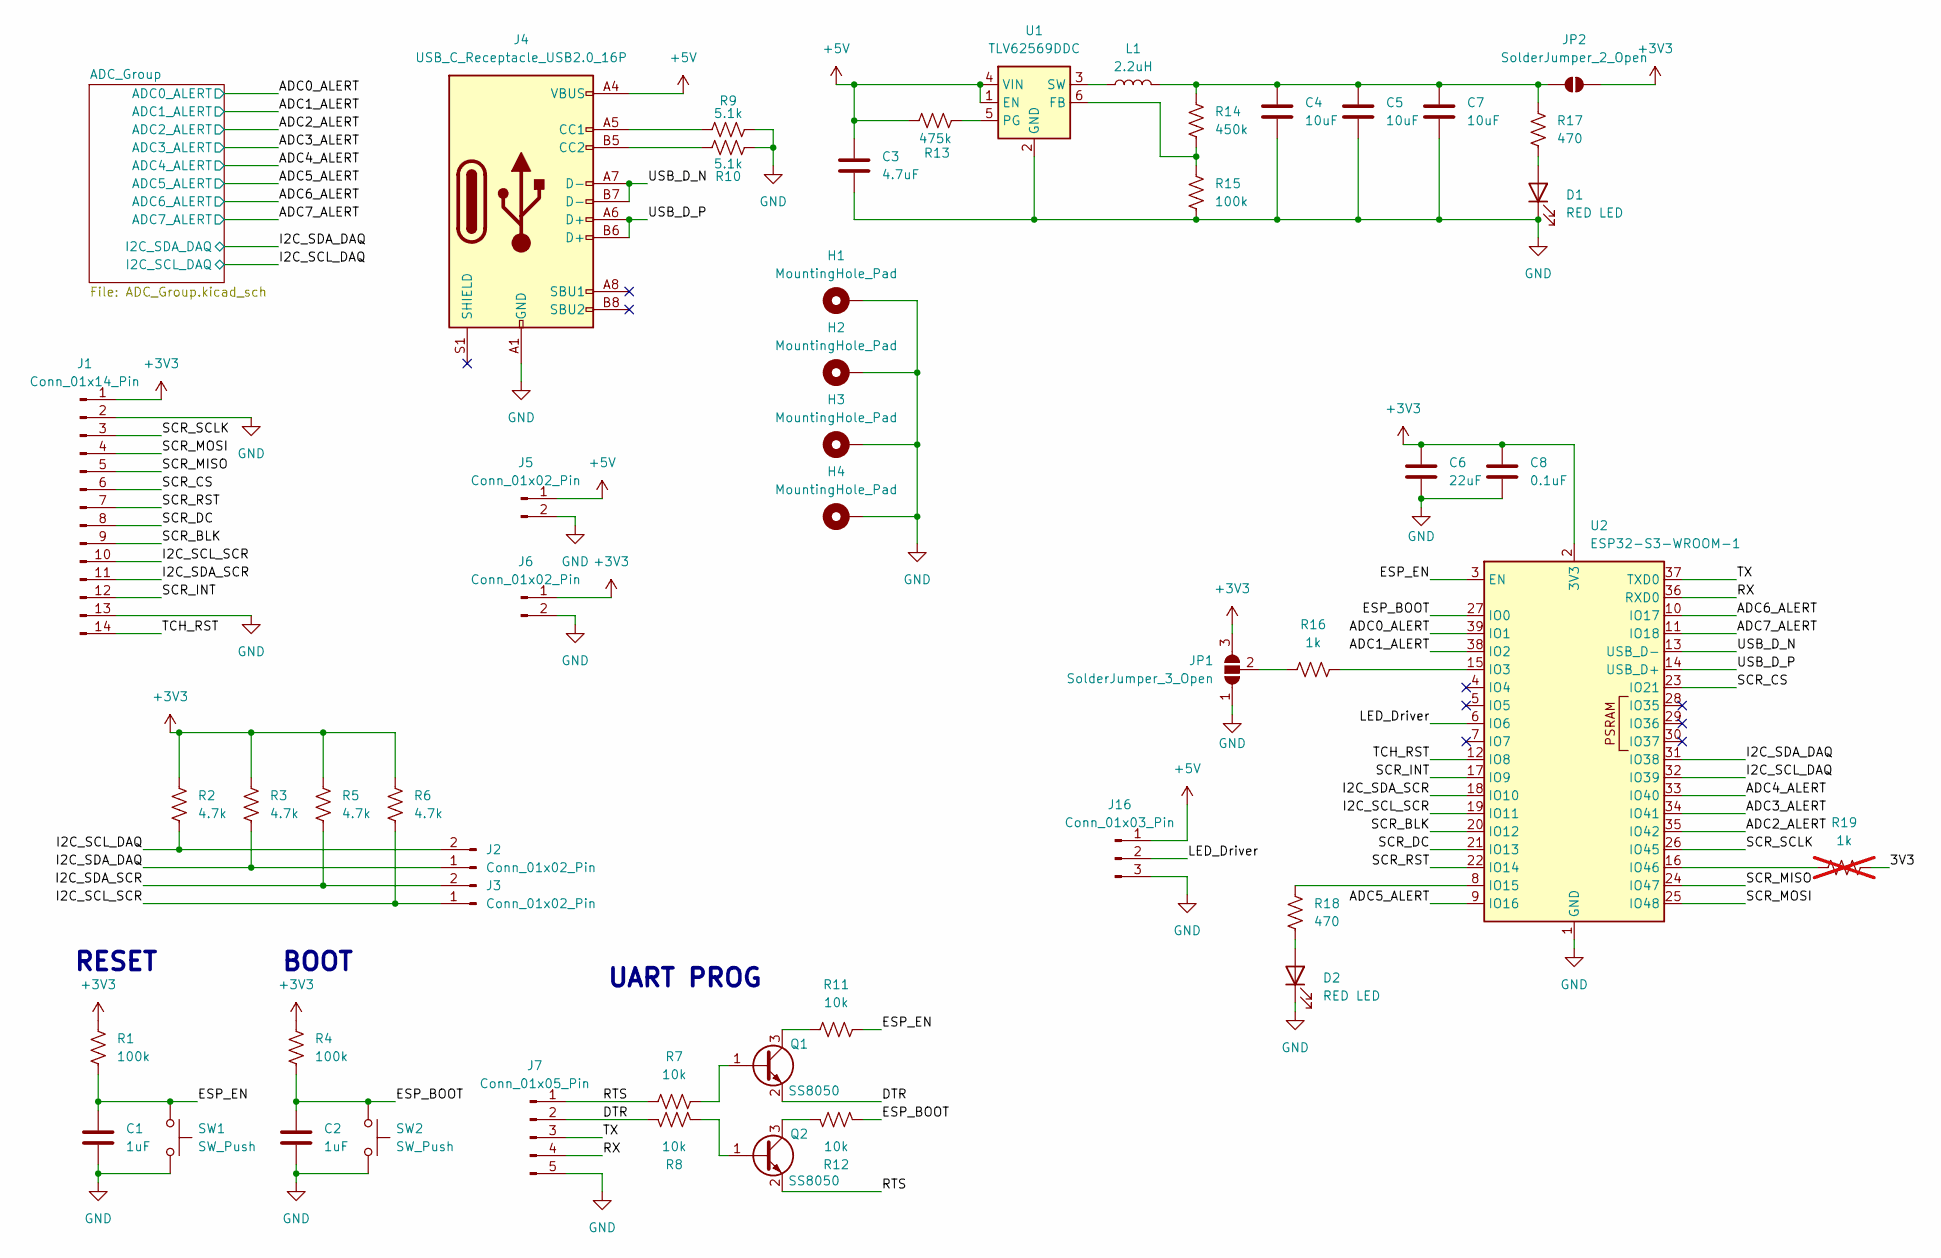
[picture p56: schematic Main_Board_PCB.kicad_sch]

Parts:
C1, C2: 1uF; C_0603_1608Metric
C3: 4.7uF; C_0603_1608Metric
C4, C5, C7: 10uF; C_0603_1608Metric
C6: 22uF; C_0603_1608Metric
C8: 0.1uF; C_0603_1608Metric
D1, D2: RED LED; LED_0603_1608Metric
H1, H2, H3, H4: MountingHole_Pad; MountingHole_3.2mm_M3_DIN965_Pad
J1: Conn_01x14_Pin; PinHeader_1x14_P2.54mm_Vertical
J2, J3, J5, J6: Conn_01x02_Pin; PinHeader_1x02_P2.54mm_Vertical
J4: USB_C_Receptacle_USB2.0_16P; USB_C_Receptacle_G-Switch_GT-USB-7010ASV
J7: Conn_01x05_Pin; PinHeader_1x05_P2.54mm_Vertical
J16: Conn_01x03_Pin; PinHeader_1x03_P2.54mm_Vertical
JP1: SolderJumper_3_Open; SolderJumper-3_P1.3mm_Open_Pad1.0x1.5mm
JP2: SolderJumper_2_Open; SolderJumper-2_P1.3mm_Open_Pad1.0x1.5mm
L1: 2.2uH; L_Coilcraft_1008HQ_2520Metric
Q1, Q2: SS8050; SOT-23
R1, R4, R15: 100k; R_0603_1608Metric
R2, R3, R5, R6: 4.7k; R_0603_1608Metric
R7, R8, R11, R12: 10k; R_0603_1608Metric
R9, R10: 5.1k; R_0603_1608Metric
R13: 475k; R_0603_1608Metric
R14: 450k; R_0603_1608Metric
R16: 1k; R_0603_1608Metric
R17, R18: 470; R_0603_1608Metric
R19: 1k; R_0603_1608Metric; not fitted
SW1, SW2: SW_Push; SW_TH_Tactile_Omron_B3F-100x
U1: TLV62569DDC; SOT-23-6
U2: ESP32-S3-WROOM-1

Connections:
+3V3: C6.2, C8.2, J1.1, J6.1, JP1.3 (B), JP2.2 (B), R1.1, R2.2, R3.2, R4.1, R5.2, R6.2, U2.2 (3V3); also elsewhere on the board
+5V: C3.2, J4.A4 (VBUS), J4.A9 (VBUS), J4.B4 (VBUS), J4.B9 (VBUS), J5.1, J16.1, R13.2, U1.1 (EN), U1.4 (VIN)
/3V3: R19.2
/ADC0_ALERT: U2.39 (IO1); also elsewhere on the board
/ADC1_ALERT: U2.38 (IO2); also elsewhere on the board
/ADC2_ALERT: U2.35 (IO42); also elsewhere on the board
/ADC3_ALERT: U2.34 (IO41); also elsewhere on the board
/ADC4_ALERT: U2.33 (IO40); also elsewhere on the board
/ADC5_ALERT: U2.9 (IO16); also elsewhere on the board
/ADC6_ALERT: U2.10 (IO17); also elsewhere on the board
/ADC7_ALERT: U2.11 (IO18); also elsewhere on the board
/DTR: J7.2, Q1.2 (E), R8.1
/ESP_BOOT: C2.1, R4.2, R12.2, SW2.1, U2.27 (IO0)
/ESP_EN: C1.1, R1.2, R11.2, SW1.1, U2.3 (EN)
/I2C_SCL_DAQ: J2.2, R2.1, U2.32 (IO39); also elsewhere on the board
/I2C_SCL_SCR: J1.10, J3.1, R6.1, U2.19 (IO11)
/I2C_SDA_DAQ: J2.1, R3.1, U2.31 (IO38); also elsewhere on the board
/I2C_SDA_SCR: J1.11, J3.2, R5.1, U2.18 (IO10)
/LED_Driver: J16.2, U2.6 (IO6)
/RTS: J7.1, Q2.2 (E), R7.1
/RX: J7.4, U2.36 (RXD0)
/SCR_BLK: J1.9, U2.20 (IO12)
/SCR_CS: J1.6, U2.23 (IO21)
/SCR_DC: J1.8, U2.21 (IO13)
/SCR_INT: J1.12, U2.17 (IO9)
/SCR_MISO: J1.5, U2.24 (IO47)
/SCR_MOSI: J1.4, U2.25 (IO48)
/SCR_RST: J1.7, U2.22 (IO14)
/SCR_SCLK: J1.3, U2.26 (IO45)
/TCH_RST: J1.14, U2.12 (IO8)
/TX: J7.3, U2.37 (TXD0)
/USB_D_N: J4.A7 (D-), J4.B7 (D-), U2.13 (USB_D-)
/USB_D_P: J4.A6 (D+), J4.B6 (D+), U2.14 (USB_D+)
GND: C1.2, C2.2, C3.1, C4.1, C5.1, C6.1, C7.1, C8.1, D1.1 (K), D2.1 (K), H1.1, H2.1, H3.1, H4.1, J1.2, J1.13, J4.A1 (GND), J4.A12 (GND), J4.B1 (GND), J4.B12 (GND), J5.2, J6.2, J7.5, J16.3, JP1.1 (A), R9.2, R10.1, R15.2, SW1.2, SW2.2, U1.2 (GND), U2.1 (GND), U2.40 (GND), U2.41 (GND); also elsewhere on the board
unnamed: D1.2 (A), R17.2
unnamed: D2.2 (A), R18.2
unnamed: J4.A5 (CC1), R9.1
unnamed: J4.B5 (CC2), R10.2
unnamed: JP1.2 (C), R16.1
unnamed: C4.2, C5.2, C7.2, JP2.1 (A), L1.2, R14.1, R17.1
unnamed: Q1.1 (B), R7.2
unnamed: Q1.3 (C), R11.1
unnamed: Q2.1 (B), R8.2
unnamed: Q2.3 (C), R12.1
unnamed: R14.2, R15.1, U1.6 (FB)
unnamed: R13.1, U1.5 (PG)
unnamed: L1.1, U1.3 (SW)
unnamed: R16.2, U2.15 (IO3)
unnamed: R18.1, U2.8 (IO15)
unnamed: R19.1, U2.16 (IO46)

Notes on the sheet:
BOOT
UART PROG
RESET

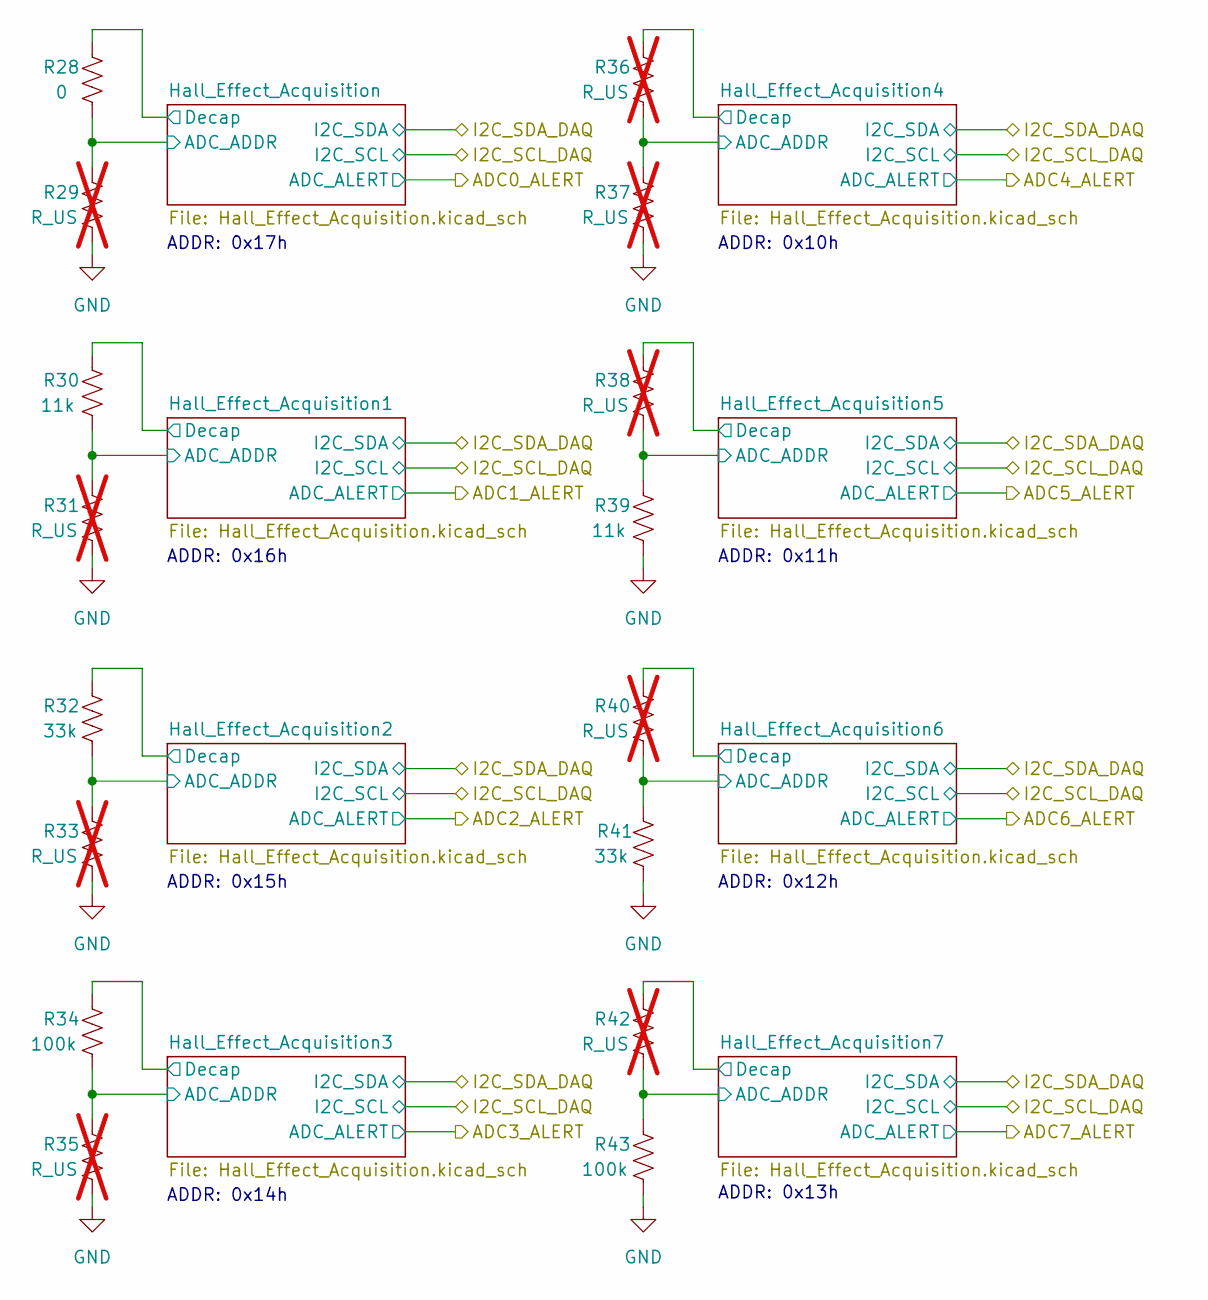
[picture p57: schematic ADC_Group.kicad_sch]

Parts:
R28: 0; R_0603_1608Metric
R29, R31, R33, R35, R36, R37, R38, R40, R42: R_US; R_0603_1608Metric; not fitted
R30, R39: 11k; R_0603_1608Metric
R32, R41: 33k; R_0603_1608Metric
R34, R43: 100k; R_0603_1608Metric

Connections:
/ADC_Group/Hall_Effect_Acquisition1/ADC_ADDR: R30.2, R31.1; also elsewhere on the board
/ADC_Group/Hall_Effect_Acquisition1/Decap: R30.1; also elsewhere on the board
/ADC_Group/Hall_Effect_Acquisition2/ADC_ADDR: R32.2, R33.1; also elsewhere on the board
/ADC_Group/Hall_Effect_Acquisition2/Decap: R32.1; also elsewhere on the board
/ADC_Group/Hall_Effect_Acquisition3/ADC_ADDR: R34.2, R35.1; also elsewhere on the board
/ADC_Group/Hall_Effect_Acquisition3/Decap: R34.1; also elsewhere on the board
/ADC_Group/Hall_Effect_Acquisition4/ADC_ADDR: R36.2, R37.1; also elsewhere on the board
/ADC_Group/Hall_Effect_Acquisition4/Decap: R36.1; also elsewhere on the board
/ADC_Group/Hall_Effect_Acquisition5/ADC_ADDR: R38.2, R39.1; also elsewhere on the board
/ADC_Group/Hall_Effect_Acquisition5/Decap: R38.1; also elsewhere on the board
/ADC_Group/Hall_Effect_Acquisition6/ADC_ADDR: R40.2, R41.1; also elsewhere on the board
/ADC_Group/Hall_Effect_Acquisition6/Decap: R40.1; also elsewhere on the board
/ADC_Group/Hall_Effect_Acquisition7/ADC_ADDR: R42.2, R43.1; also elsewhere on the board
/ADC_Group/Hall_Effect_Acquisition7/Decap: R42.1; also elsewhere on the board
/ADC_Group/Hall_Effect_Acquisition/ADC_ADDR: R28.2, R29.1; also elsewhere on the board
/ADC_Group/Hall_Effect_Acquisition/Decap: R28.1; also elsewhere on the board
GND: R29.2, R31.2, R33.2, R35.2, R37.2, R39.2, R41.2, R43.2; also elsewhere on the board

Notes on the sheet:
ADDR: 0x16h
ADDR: 0x17h
ADDR: 0x14h
ADDR: 0x13h
ADDR: 0x12h
ADDR: 0x10h
ADDR: 0x15h
ADDR: 0x11h

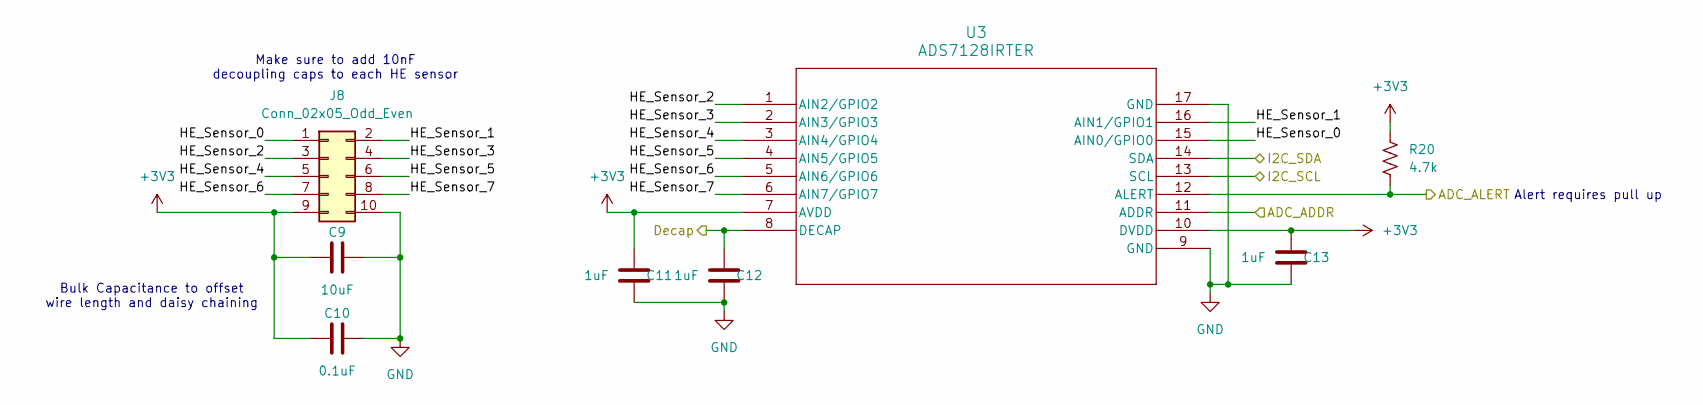
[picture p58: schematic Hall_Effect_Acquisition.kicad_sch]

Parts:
C9: 10uF; C_0603_1608Metric
C10: 0.1uF; C_0603_1608Metric
C11, C12, C13: 1uF; C_0603_1608Metric
J8: Conn_02x05_Odd_Even; AMPHENOL_67997-410HLF
R20: 4.7k; R_0603_1608Metric
U3: ADS7128IRTER; WQFN16_RTE_TEX-M

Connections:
+3V3: C9.2, C10.2, C11.2, C13.2, J8.9, R20.2, U3.7 (AVDD), U3.10 (DVDD); also elsewhere on the board
/ADC0_ALERT: R20.1, U3.12 (ALERT); also elsewhere on the board
/ADC_Group/Hall_Effect_Acquisition/ADC_ADDR: U3.11 (ADDR); also elsewhere on the board
/ADC_Group/Hall_Effect_Acquisition/Decap: C12.2, U3.8 (DECAP); also elsewhere on the board
/ADC_Group/Hall_Effect_Acquisition/HE_Sensor_0: J8.1, U3.15 (AIN0/GPIO0)
/ADC_Group/Hall_Effect_Acquisition/HE_Sensor_1: J8.2, U3.16 (AIN1/GPIO1)
/ADC_Group/Hall_Effect_Acquisition/HE_Sensor_2: J8.3, U3.1 (AIN2/GPIO2)
/ADC_Group/Hall_Effect_Acquisition/HE_Sensor_3: J8.4, U3.2 (AIN3/GPIO3)
/ADC_Group/Hall_Effect_Acquisition/HE_Sensor_4: J8.5, U3.3 (AIN4/GPIO4)
/ADC_Group/Hall_Effect_Acquisition/HE_Sensor_5: J8.6, U3.4 (AIN5/GPIO5)
/ADC_Group/Hall_Effect_Acquisition/HE_Sensor_6: J8.7, U3.5 (AIN6/GPIO6)
/ADC_Group/Hall_Effect_Acquisition/HE_Sensor_7: J8.8, U3.6 (AIN7/GPIO7)
/I2C_SCL_DAQ: U3.13 (SCL); also elsewhere on the board
/I2C_SDA_DAQ: U3.14 (SDA); also elsewhere on the board
GND: C9.1, C10.1, C11.1, C12.1, C13.1, J8.10, U3.9 (GND), U3.17 (GND); also elsewhere on the board

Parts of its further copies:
C14, C19, C24, C29, C34, C39, C44: 10uF; C_0603_1608Metric
C15, C20, C25, C30, C35, C40, C45: 0.1uF; C_0603_1608Metric
C16, C17, C18, C21, C22, C23, C26, C27, C28, C31, C32, C33, C36, C37, C38, C41, C42, C43, C46, C47, C48: 1uF; C_0603_1608Metric
J9, J10, J11, J12, J13, J14, J15: Conn_02x05_Odd_Even; AMPHENOL_67997-410HLF
R21, R22, R23, R24, R25, R26, R27: 4.7k; R_0603_1608Metric
U4, U5, U6, U7, U8, U9, U10: ADS7128IRTER; WQFN16_RTE_TEX-M

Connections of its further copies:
+3V3: C14.2, C15.2, C16.2, C18.2, C19.2, C20.2, C21.2, C23.2, C24.2, C25.2, C26.2, C28.2, C29.2, C30.2, C31.2, C33.2, C34.2, C35.2, C36.2, C38.2, C39.2, C40.2, C41.2, C43.2, C44.2, C45.2, C46.2, C48.2, J9.9, J10.9, J11.9, J12.9, J13.9, J14.9, J15.9, R21.2, R22.2, R23.2, R24.2, R25.2, R26.2, R27.2, U4.7 (AVDD), U4.10 (DVDD), U5.7 (AVDD), U5.10 (DVDD), U6.7 (AVDD), U6.10 (DVDD), U7.7 (AVDD), U7.10 (DVDD), U8.7 (AVDD), U8.10 (DVDD), U9.7 (AVDD), U9.10 (DVDD), U10.7 (AVDD), U10.10 (DVDD); also elsewhere on the board
/ADC1_ALERT: R21.1, U4.12 (ALERT); also elsewhere on the board
/ADC2_ALERT: R22.1, U5.12 (ALERT); also elsewhere on the board
/ADC3_ALERT: R23.1, U6.12 (ALERT); also elsewhere on the board
/ADC4_ALERT: R24.1, U7.12 (ALERT); also elsewhere on the board
/ADC5_ALERT: R25.1, U8.12 (ALERT); also elsewhere on the board
/ADC6_ALERT: R26.1, U9.12 (ALERT); also elsewhere on the board
/ADC7_ALERT: R27.1, U10.12 (ALERT); also elsewhere on the board
/ADC_Group/Hall_Effect_Acquisition1/ADC_ADDR: U4.11 (ADDR); also elsewhere on the board
/ADC_Group/Hall_Effect_Acquisition1/Decap: C17.2, U4.8 (DECAP); also elsewhere on the board
/ADC_Group/Hall_Effect_Acquisition1/HE_Sensor_0: J9.1, U4.15 (AIN0/GPIO0)
/ADC_Group/Hall_Effect_Acquisition1/HE_Sensor_1: J9.2, U4.16 (AIN1/GPIO1)
/ADC_Group/Hall_Effect_Acquisition1/HE_Sensor_2: J9.3, U4.1 (AIN2/GPIO2)
/ADC_Group/Hall_Effect_Acquisition1/HE_Sensor_3: J9.4, U4.2 (AIN3/GPIO3)
/ADC_Group/Hall_Effect_Acquisition1/HE_Sensor_4: J9.5, U4.3 (AIN4/GPIO4)
/ADC_Group/Hall_Effect_Acquisition1/HE_Sensor_5: J9.6, U4.4 (AIN5/GPIO5)
/ADC_Group/Hall_Effect_Acquisition1/HE_Sensor_6: J9.7, U4.5 (AIN6/GPIO6)
/ADC_Group/Hall_Effect_Acquisition1/HE_Sensor_7: J9.8, U4.6 (AIN7/GPIO7)
/ADC_Group/Hall_Effect_Acquisition2/ADC_ADDR: U5.11 (ADDR); also elsewhere on the board
/ADC_Group/Hall_Effect_Acquisition2/Decap: C22.2, U5.8 (DECAP); also elsewhere on the board
/ADC_Group/Hall_Effect_Acquisition2/HE_Sensor_0: J10.1, U5.15 (AIN0/GPIO0)
/ADC_Group/Hall_Effect_Acquisition2/HE_Sensor_1: J10.2, U5.16 (AIN1/GPIO1)
/ADC_Group/Hall_Effect_Acquisition2/HE_Sensor_2: J10.3, U5.1 (AIN2/GPIO2)
/ADC_Group/Hall_Effect_Acquisition2/HE_Sensor_3: J10.4, U5.2 (AIN3/GPIO3)
/ADC_Group/Hall_Effect_Acquisition2/HE_Sensor_4: J10.5, U5.3 (AIN4/GPIO4)
/ADC_Group/Hall_Effect_Acquisition2/HE_Sensor_5: J10.6, U5.4 (AIN5/GPIO5)
/ADC_Group/Hall_Effect_Acquisition2/HE_Sensor_6: J10.7, U5.5 (AIN6/GPIO6)
/ADC_Group/Hall_Effect_Acquisition2/HE_Sensor_7: J10.8, U5.6 (AIN7/GPIO7)
/ADC_Group/Hall_Effect_Acquisition3/ADC_ADDR: U6.11 (ADDR); also elsewhere on the board
/ADC_Group/Hall_Effect_Acquisition3/Decap: C27.2, U6.8 (DECAP); also elsewhere on the board
/ADC_Group/Hall_Effect_Acquisition3/HE_Sensor_0: J11.1, U6.15 (AIN0/GPIO0)
/ADC_Group/Hall_Effect_Acquisition3/HE_Sensor_1: J11.2, U6.16 (AIN1/GPIO1)
/ADC_Group/Hall_Effect_Acquisition3/HE_Sensor_2: J11.3, U6.1 (AIN2/GPIO2)
/ADC_Group/Hall_Effect_Acquisition3/HE_Sensor_3: J11.4, U6.2 (AIN3/GPIO3)
/ADC_Group/Hall_Effect_Acquisition3/HE_Sensor_4: J11.5, U6.3 (AIN4/GPIO4)
/ADC_Group/Hall_Effect_Acquisition3/HE_Sensor_5: J11.6, U6.4 (AIN5/GPIO5)
/ADC_Group/Hall_Effect_Acquisition3/HE_Sensor_6: J11.7, U6.5 (AIN6/GPIO6)
/ADC_Group/Hall_Effect_Acquisition3/HE_Sensor_7: J11.8, U6.6 (AIN7/GPIO7)
/ADC_Group/Hall_Effect_Acquisition4/ADC_ADDR: U7.11 (ADDR); also elsewhere on the board
/ADC_Group/Hall_Effect_Acquisition4/Decap: C32.2, U7.8 (DECAP); also elsewhere on the board
/ADC_Group/Hall_Effect_Acquisition4/HE_Sensor_0: J12.1, U7.15 (AIN0/GPIO0)
/ADC_Group/Hall_Effect_Acquisition4/HE_Sensor_1: J12.2, U7.16 (AIN1/GPIO1)
/ADC_Group/Hall_Effect_Acquisition4/HE_Sensor_2: J12.3, U7.1 (AIN2/GPIO2)
/ADC_Group/Hall_Effect_Acquisition4/HE_Sensor_3: J12.4, U7.2 (AIN3/GPIO3)
/ADC_Group/Hall_Effect_Acquisition4/HE_Sensor_4: J12.5, U7.3 (AIN4/GPIO4)
/ADC_Group/Hall_Effect_Acquisition4/HE_Sensor_5: J12.6, U7.4 (AIN5/GPIO5)
/ADC_Group/Hall_Effect_Acquisition4/HE_Sensor_6: J12.7, U7.5 (AIN6/GPIO6)
/ADC_Group/Hall_Effect_Acquisition4/HE_Sensor_7: J12.8, U7.6 (AIN7/GPIO7)
/ADC_Group/Hall_Effect_Acquisition5/ADC_ADDR: U8.11 (ADDR); also elsewhere on the board
/ADC_Group/Hall_Effect_Acquisition5/Decap: C37.2, U8.8 (DECAP); also elsewhere on the board
/ADC_Group/Hall_Effect_Acquisition5/HE_Sensor_0: J13.1, U8.15 (AIN0/GPIO0)
/ADC_Group/Hall_Effect_Acquisition5/HE_Sensor_1: J13.2, U8.16 (AIN1/GPIO1)
/ADC_Group/Hall_Effect_Acquisition5/HE_Sensor_2: J13.3, U8.1 (AIN2/GPIO2)
/ADC_Group/Hall_Effect_Acquisition5/HE_Sensor_3: J13.4, U8.2 (AIN3/GPIO3)
/ADC_Group/Hall_Effect_Acquisition5/HE_Sensor_4: J13.5, U8.3 (AIN4/GPIO4)
/ADC_Group/Hall_Effect_Acquisition5/HE_Sensor_5: J13.6, U8.4 (AIN5/GPIO5)
/ADC_Group/Hall_Effect_Acquisition5/HE_Sensor_6: J13.7, U8.5 (AIN6/GPIO6)
/ADC_Group/Hall_Effect_Acquisition5/HE_Sensor_7: J13.8, U8.6 (AIN7/GPIO7)
/ADC_Group/Hall_Effect_Acquisition6/ADC_ADDR: U9.11 (ADDR); also elsewhere on the board
/ADC_Group/Hall_Effect_Acquisition6/Decap: C42.2, U9.8 (DECAP); also elsewhere on the board
/ADC_Group/Hall_Effect_Acquisition6/HE_Sensor_0: J14.1, U9.15 (AIN0/GPIO0)
/ADC_Group/Hall_Effect_Acquisition6/HE_Sensor_1: J14.2, U9.16 (AIN1/GPIO1)
/ADC_Group/Hall_Effect_Acquisition6/HE_Sensor_2: J14.3, U9.1 (AIN2/GPIO2)
/ADC_Group/Hall_Effect_Acquisition6/HE_Sensor_3: J14.4, U9.2 (AIN3/GPIO3)
/ADC_Group/Hall_Effect_Acquisition6/HE_Sensor_4: J14.5, U9.3 (AIN4/GPIO4)
/ADC_Group/Hall_Effect_Acquisition6/HE_Sensor_5: J14.6, U9.4 (AIN5/GPIO5)
/ADC_Group/Hall_Effect_Acquisition6/HE_Sensor_6: J14.7, U9.5 (AIN6/GPIO6)
/ADC_Group/Hall_Effect_Acquisition6/HE_Sensor_7: J14.8, U9.6 (AIN7/GPIO7)
/ADC_Group/Hall_Effect_Acquisition7/ADC_ADDR: U10.11 (ADDR); also elsewhere on the board
/ADC_Group/Hall_Effect_Acquisition7/Decap: C47.2, U10.8 (DECAP); also elsewhere on the board
/ADC_Group/Hall_Effect_Acquisition7/HE_Sensor_0: J15.1, U10.15 (AIN0/GPIO0)
/ADC_Group/Hall_Effect_Acquisition7/HE_Sensor_1: J15.2, U10.16 (AIN1/GPIO1)
/ADC_Group/Hall_Effect_Acquisition7/HE_Sensor_2: J15.3, U10.1 (AIN2/GPIO2)
/ADC_Group/Hall_Effect_Acquisition7/HE_Sensor_3: J15.4, U10.2 (AIN3/GPIO3)
/ADC_Group/Hall_Effect_Acquisition7/HE_Sensor_4: J15.5, U10.3 (AIN4/GPIO4)
/ADC_Group/Hall_Effect_Acquisition7/HE_Sensor_5: J15.6, U10.4 (AIN5/GPIO5)
/ADC_Group/Hall_Effect_Acquisition7/HE_Sensor_6: J15.7, U10.5 (AIN6/GPIO6)
/ADC_Group/Hall_Effect_Acquisition7/HE_Sensor_7: J15.8, U10.6 (AIN7/GPIO7)
/I2C_SCL_DAQ: U4.13 (SCL), U5.13 (SCL), U6.13 (SCL), U7.13 (SCL), U8.13 (SCL), U9.13 (SCL), U10.13 (SCL); also elsewhere on the board
/I2C_SDA_DAQ: U4.14 (SDA), U5.14 (SDA), U6.14 (SDA), U7.14 (SDA), U8.14 (SDA), U9.14 (SDA), U10.14 (SDA); also elsewhere on the board
GND: C14.1, C15.1, C16.1, C17.1, C18.1, C19.1, C20.1, C21.1, C22.1, C23.1, C24.1, C25.1, C26.1, C27.1, C28.1, C29.1, C30.1, C31.1, C32.1, C33.1, C34.1, C35.1, C36.1, C37.1, C38.1, C39.1, C40.1, C41.1, C42.1, C43.1, C44.1, C45.1, C46.1, C47.1, C48.1, J9.10, J10.10, J11.10, J12.10, J13.10, J14.10, J15.10, U4.9 (GND), U4.17 (GND), U5.9 (GND), U5.17 (GND), U6.9 (GND), U6.17 (GND), U7.9 (GND), U7.17 (GND), U8.9 (GND), U8.17 (GND), U9.9 (GND), U9.17 (GND), U10.9 (GND), U10.17 (GND); also elsewhere on the board

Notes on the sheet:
Make sure to add 10nF decoupling caps to each HE sensor
Alert requires pull up
Bulk Capacitance to offset wire length and daisy chaining

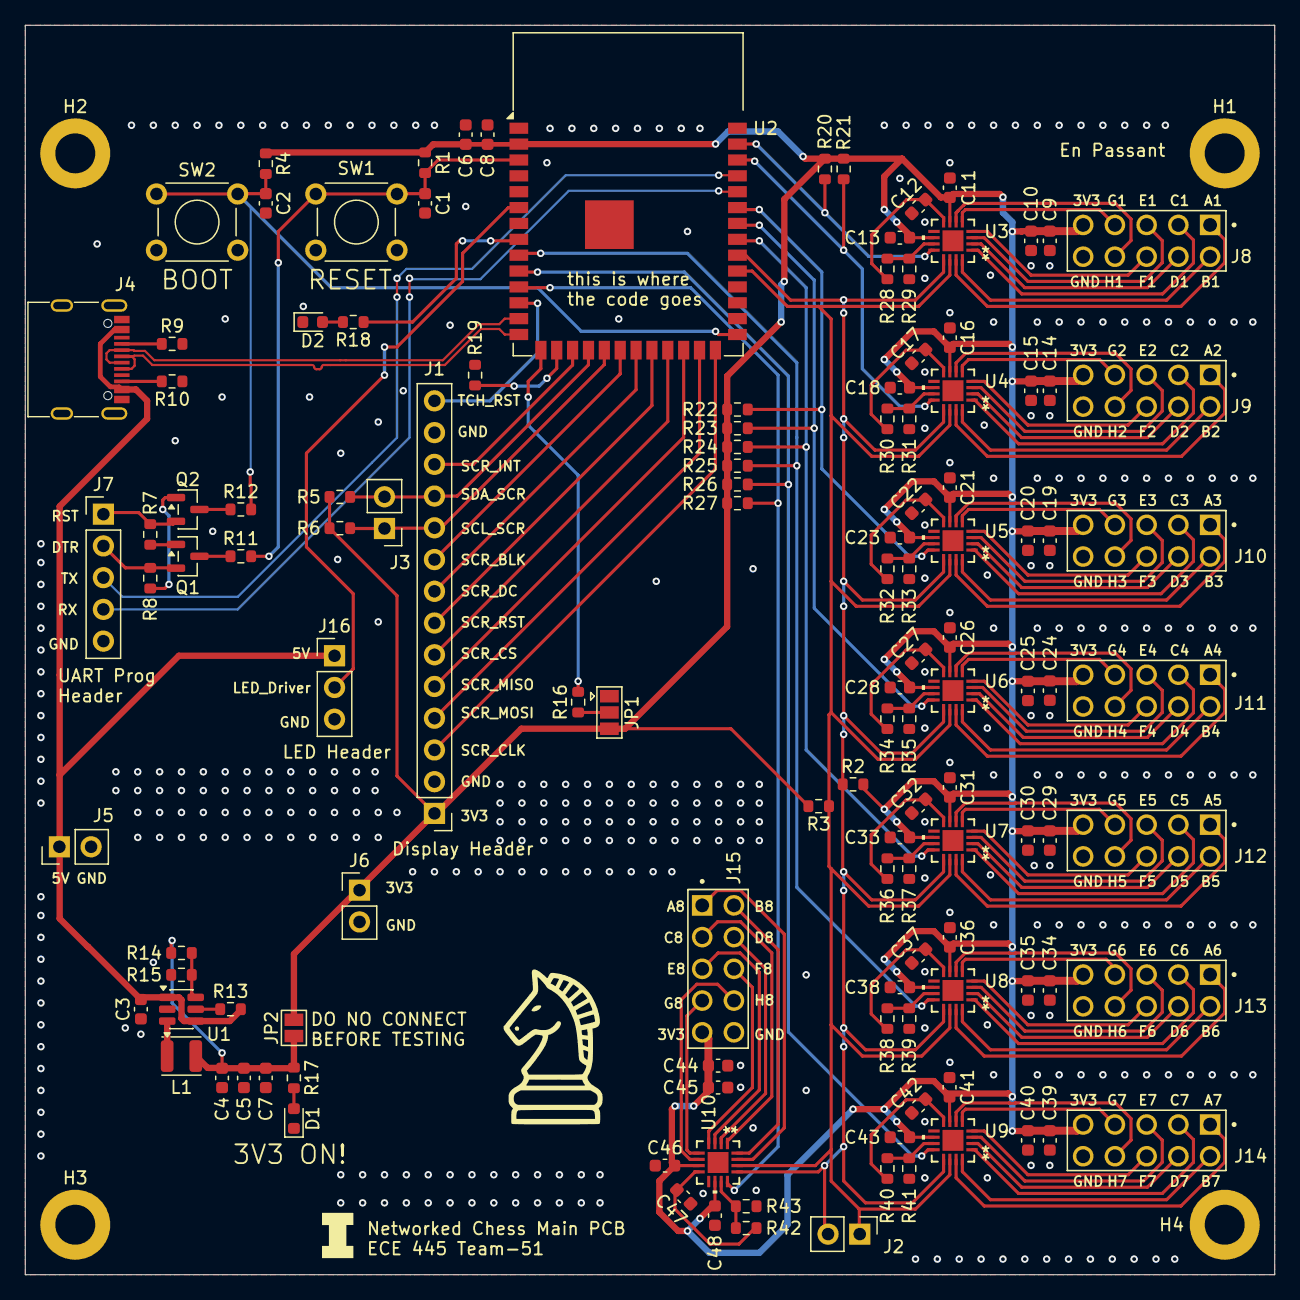
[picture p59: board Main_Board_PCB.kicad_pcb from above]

Board: 2 copper layers, 100.0 x 100.0 mm, 130 parts (0 on the bottom side), 129 nets.

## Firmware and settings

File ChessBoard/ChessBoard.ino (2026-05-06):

#include <Arduino.h>
#include <SPI.h>
#include <Wire.h>
#include <WiFi.h>

#include "headers.h"
#include "display_driver.h"
#include "api_connect.h"
#include "ADC_driver.h"
#include "wifi_manager.h"
#include "gameloop.h"

#include "DFRobot_GDL.h"
#include "DFRobot_Touch.h"

// ===================== GLOBAL OBJECTS =====================
DFRobot_Touch_GT911_IPS touch(0x5D, SCR_TCH_RST, SCR_INT);
DFRobot_ST7365P_320x480_HW_SPI screen(SCR_DC, SCR_CS, SCR_RST, SCR_BLK);

// ===================== BUTTON REGIONS =====================
// Menu buttons (landscape 480×320) — 4 rows
#define JOIN_BTN_X 50
#define JOIN_BTN_Y 55
#define JOIN_BTN_W 380
#define JOIN_BTN_H 48

#define CREATE_BTN_X 50
#define CREATE_BTN_Y 112
#define CREATE_BTN_W 380
#define CREATE_BTN_H 48

#define VSAI_BTN_X 50
#define VSAI_BTN_Y 169
#define VSAI_BTN_W 380
#define VSAI_BTN_H 48

#define ADCID_BTN_X 50
#define ADCID_BTN_Y 226
#define ADCID_BTN_W 380
#define ADCID_BTN_H 48

// Confirm / Cancel in right info panel of the game screen
#define CONFIRM_BTN_X 272
#define CONFIRM_BTN_Y 200
#define CONFIRM_BTN_W 192
#define CONFIRM_BTN_H 44

#define CANCEL_BTN_X 272
#define CANCEL_BTN_Y 252
#define CANCEL_BTN_W 192
#define CANCEL_BTN_H 44

#define GAME_MSG_MAX_LEN 200 // matches server-side 200-char limit (was 96)

// ===================== STATE =====================
enum ScreenState
{
  MENU,
  GAME,
  BOARD_TEST,
  EDGE_CASE_TEST,
  WIFI_LIST,
  WIFI_PASS_SCREEN,
  TIMER_MODE_SELECT,
  AI_MODE_SELECT
};
ScreenState currentScreen = MENU;
bool wifiConnected = false;
bool isAiGame = false; // true when playing against Stockfish AI
unsigned long menuShownAt = 0;
unsigned long lastBoardTestUpdate = 0;

// Game screen display tracking
static String gs_lastRenderedFEN;
static bool gs_lastConfirmState = false;
static bool gs_lastGameOver = false;
static bool gs_lastCheckState = false;
static String gs_lastIncomingFEN;
static String gs_lastPendingFEN;
static char gs_liftSquare[3] = {0};
static bool gs_liftShown = false;
static String gs_lastTurnStatus;     // tracks last status bar turn message
static String gs_lastOverlayPhysFEN; // tracks last physical FEN used for display overlay
static bool gs_lastPromoState = false;
static char gs_messageBuf[GAME_MSG_MAX_LEN + 1] = {0};
static bool gs_messageComposeActive = false;
static bool gs_messageShifted = false;
static bool gs_messageSymbols = false;

// Chat history received from the server
static ChatDisplayMsg gs_chatHistory[CHAT_MAX_DISPLAY] = {};
static int gs_chatCount = 0;
static int gs_lastMsgCount = -1;
static unsigned long gs_lastMsgPoll = 0;
#define MSG_POLL_INTERVAL_MS 5000UL

// Dirty-tracking for chat panel (avoids redrawing every loop iteration)
static int gs_lastPanelCount = -2; // -2 = never drawn
static char gs_lastPanelDraft[GAME_MSG_MAX_LEN + 1] = {0};

// Dirty-tracking for composer (avoids redrawing every loop iteration)
static bool gs_composerDrawn = false;
static char gs_lastComposerDraft[GAME_MSG_MAX_LEN + 1] = {0};
static bool gs_lastComposerShifted = false;
static bool gs_lastComposerSymbols = false;

// Timer display tracking
static unsigned long gs_lastTimerDrawMs = 0;
static bool gs_timerDirty = false;

// Hint button tracking
static int gs_hintsLeft = 3;         // hints remaining this game for the local player
static int gs_lastHintBtnDrawn = -1; // -1 = needs redraw; mirrors gs_hintsLeft when drawn

// Physical board FEN buffer (72 bytes = worst-case FEN board + null)
static char gs_boardFENBuf[72];

// WiFi manager UI state
ScannedNetwork scannedNets[WM_MAX_SCAN];
uint8_t scannedCount = 0;
char selectedSSID[WM_SSID_LEN];
char passwordBuf[WM_PASS_LEN];
bool kbShifted = false;
bool kbSymbols = false;
bool kbShowChars = false;

// ===================== FORWARD DECLARATIONS =====================
void showMenuScreen();
void showGameScreen();
void drawConfirmOverlay();
void showWifiListScreen();
void showWifiPassScreen(const char *ssid);
void handleWifiListTouch(int tx, int ty);
void handleWifiPassTouch(int tx, int ty);
void runBoardTests();
void drawBoardTestLive();
void showEdgeCaseMenuScreen();
void handleEdgeCaseTouch(int tx, int ty);
void showTimerModeScreen();
void showAiModeScreen();

// Returns true and sets outMode if (tx, ty) falls within one of the three
// timer-mode buttons.  Shared by TIMER_MODE_SELECT and AI_MODE_SELECT handlers.
static bool pickTimerButton(int tx, int ty, TimerMode &outMode)
{
  if (tx < TIMER_BTN_X || tx > TIMER_BTN_X + TIMER_BTN_W)
    return false;
  if (ty >= TIMER_BTN_UNLIM_Y && ty <= TIMER_BTN_UNLIM_Y + TIMER_BTN_H)
  {
    outMode = TIMER_NONE;
    return true;
  }
  if (ty >= TIMER_BTN_RAPID_Y && ty <= TIMER_BTN_RAPID_Y + TIMER_BTN_H)
  {
    outMode = TIMER_RAPID;
    return true;
  }
  if (ty >= TIMER_BTN_BULLET_Y && ty <= TIMER_BTN_BULLET_Y + TIMER_BTN_H)
  {
    outMode = TIMER_BULLET;
    return true;
  }
  return false;
}

// ===================== SCREEN HELPERS =====================
void showMenuScreen()
{
  currentScreen = MENU;
  drawMenuScreen(wifiConnected);

  displayButton(JOIN_BTN_X, JOIN_BTN_Y, JOIN_BTN_W, JOIN_BTN_H, COLOR_RGB565_BLUE, "Join Game");
  displayButton(CREATE_BTN_X, CREATE_BTN_Y, CREATE_BTN_W, CREATE_BTN_H, COLOR_RGB565_ORANGE, "Create Game");
  displayButton(VSAI_BTN_X, VSAI_BTN_Y, VSAI_BTN_W, VSAI_BTN_H, COLOR_RGB565_GREEN, "vs Stockfish AI");
  displayButton(ADCID_BTN_X, ADCID_BTN_Y, ADCID_BTN_W, ADCID_BTN_H, COLOR_RGB565_OLIVE, "ADC Board Test");

  menuShownAt = millis();
}

void showGameScreen()
{
  currentScreen = GAME;
  invalidateBoardCache(); // ensure full chrome + board repaint for this game session
  gs_lastRenderedFEN = "";
  gs_lastConfirmState = false;
  gs_lastGameOver = false;
  gs_lastCheckState = false;
  gs_lastIncomingFEN = "";
  gs_lastPendingFEN = "";
  gs_liftSquare[0] = 0;
  gs_liftShown = false;
  gs_lastTurnStatus = "";
  gs_lastOverlayPhysFEN = "";
  gs_lastPromoState = false;
  gs_messageBuf[0] = '\0';
  gs_messageComposeActive = false;
  gs_messageShifted = false;
  gs_messageSymbols = false;
  gs_chatCount = 0;
  gs_lastMsgCount = -1;
  gs_lastMsgPoll = 0;
  memset(gs_chatHistory, 0, sizeof(gs_chatHistory));
  gs_lastPanelCount = -2;
  gs_lastPanelDraft[0] = '\0';
  gs_composerDrawn = false;
  gs_lastComposerDraft[0] = '\0';
  gs_lastComposerShifted = false;
  gs_lastComposerSymbols = false;
  gs_timerDirty = true;
  gs_lastTimerDrawMs = 0;
  gs_hintsLeft = 3;
  gs_lastHintBtnDrawn = -1;
  // Note: the caller (touch handler) must have already called cgm_createGameNow()
  // or cgm_joinGameNow() before calling showGameScreen().
}

void showTimerModeScreen()
{
  currentScreen = TIMER_MODE_SELECT;
  drawTimerModeScreen(wifiConnected);
}

// AI difficulty selection screen — three buttons: Easy, Medium, Hard.
// After choosing, resets the game with gameMode=ai and launches the game.
void showAiModeScreen()
{
  currentScreen = AI_MODE_SELECT;
  drawAiDifficultyScreen(wifiConnected);
}

// Draw confirm / cancel buttons as an overlay on the game screen.
void drawConfirmOverlay()
{
  displayButton(CONFIRM_BTN_X, CONFIRM_BTN_Y, CONFIRM_BTN_W, CONFIRM_BTN_H,
                COLOR_RGB565_GREEN, "Confirm");
  displayButton(CANCEL_BTN_X, CANCEL_BTN_Y, CANCEL_BTN_W, CANCEL_BTN_H,
                COLOR_RGB565_RED, "Cancel");
}

void showWifiListScreen()
{
  currentScreen = WIFI_LIST;
  drawWifiListScreen(nullptr, 0, true); // show "Scanning..." placeholder
  scannedCount = wmScan(scannedNets);   // blocking scan ~2-3 s
  drawWifiListScreen(scannedNets, scannedCount, false);
}

void showWifiPassScreen(const char *ssid)
{
  currentScreen = WIFI_PASS_SCREEN;
  strncpy(selectedSSID, ssid, WM_SSID_LEN - 1);
  selectedSSID[WM_SSID_LEN - 1] = '\0';
  memset(passwordBuf, 0, sizeof(passwordBuf));
  kbShifted = false;
  kbSymbols = false;
  kbShowChars = false;
  drawPasswordScreen(selectedSSID, passwordBuf, kbShowChars, kbShifted, kbSymbols);
}

// ===================== TOUCH HANDLING =====================
static bool lastTouched = false;

void handleWifiListTouch(int tx, int ty)
{
  if (ty < 38 && tx < 80)
  {
    showMenuScreen();
    return;
  } // Back
  if (ty < 38 && tx > 360)
  {
    showWifiListScreen();
    return;
  } // Rescan

  if (ty >= WIFLIST_ROW_Y_START && scannedCount > 0)
  {
    int idx = (ty - WIFLIST_ROW_Y_START) / WIFLIST_ROW_H;
    if (idx < 0 || idx >= (int)scannedCount)
      return;
    showWifiPassScreen(scannedNets[idx].ssid);
  }
}

void handleWifiPassTouch(int tx, int ty)
{
  if (ty < 38 && tx < 80)
  {
    showWifiListScreen();
    return;
  } // Back

  // Show / Hide password toggle (landscape: x 396–474)
  if (tx >= 396 && tx <= 474 && ty >= 72 && ty <= 110)
  {
    kbShowChars = !kbShowChars;
    drawPasswordField(passwordBuf, kbShowChars);
    return;
  }

  if (ty < KB_ROW1_Y)
    return;
  char key = keyboardHitTest(tx, ty, kbSymbols);
  if (key == 0)
    return;

  if (key == '\t') // shift toggle
  {
    kbShifted = !kbShifted;
    drawKeyboard(kbShifted, kbSymbols);
  }
  else if (key == 0x01) // symbols page toggle
  {
    kbSymbols = !kbSymbols;
    kbShifted = false;
    drawKeyboard(kbShifted, kbSymbols);
  }
  else if (key == '\b') // backspace
  {
    int len = strlen(passwordBuf);
    if (len > 0)
    {
      passwordBuf[len - 1] = '\0';
      drawPasswordField(passwordBuf, kbShowChars);
    }
  }
  else if (key == '\n') // Done
  {
    if (strlen(passwordBuf) == 0)
      return;
    displayStatusBar("Connecting...", COLOR_RGB565_BLUE);
    if (wmConnect(selectedSSID, passwordBuf))
    {
      wifiConnected = true;
      displayStatusBar("Connected!", COLOR_RGB565_GREEN);
      delay(1200);
      showMenuScreen();
    }
    else
    {
      displayStatusBar("Connection failed - check password", COLOR_RGB565_RED);
    }
  }
  else // printable character
  {
    int len = strlen(passwordBuf);
    if (len < WM_PASS_LEN - 1)
    {
      char ch = (!kbSymbols && kbShifted) ? (char)toupper(key) : key;
      passwordBuf[len] = ch;
      passwordBuf[len + 1] = '\0';
      drawPasswordField(passwordBuf, kbShowChars);
      if (kbShifted && !kbSymbols) // one-shot shift
      {
        kbShifted = false;
        drawKeyboard(kbShifted, kbSymbols);
      }
    }
  }
}
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
void loop()
{
  handleTouch();

  unsigned long now = millis();

  if (currentScreen == GAME)
  {
    // Refresh WiFi status each frame so display reflects reconnects
    bool wifiNow = (WiFi.status() == WL_CONNECTED);

    // 1. Read physical board state and feed it to the FSM
    // Pass orientation so ch7 always reads as the user's closest rank.
    readBoardFEN(gs_boardFENBuf, cgm_isLocalPlayerWhite());
    cgm_setPhysicalBoardFEN(String(gs_boardFENBuf));

    // 2. Tick the game FSM
    cgm_tick();

    // ----------------------------------------------------------------
    // 2b. Update display overlay for physical/logical mismatches
    // ----------------------------------------------------------------
    {
      const String &committed = cgm_getCommittedFEN();
      String physNow(gs_boardFENBuf);
      if (committed.length() > 0 && physNow != gs_lastOverlayPhysFEN)
      {
        gs_lastOverlayPhysFEN = physNow;
        drawBoardSyncOverlay(committed, physNow, !cgm_isLocalPlayerWhite());
      }
    }

    // ----------------------------------------------------------------
    // 2c. Promotion picker — shown once when the state is entered
    // ----------------------------------------------------------------
    if (cgm_isChoosingPromotion() && !gs_lastPromoState)
    {
      gs_lastPromoState = true;
      drawPromotionPicker(cgm_isLocalPlayerWhite());
    }
    else if (!cgm_isChoosingPromotion() && gs_lastPromoState)
    {
      gs_lastPromoState = false;
      // Board will be redrawn naturally when pendingFEN changes after validation
    }

    // ----------------------------------------------------------------
    // 3. Game-over screen (highest priority — drawn once, stays up)
    // ----------------------------------------------------------------
    if (cgm_isGameOver() && !gs_lastGameOver)
    {
      gs_lastGameOver = true;
      drawGameOverScreen(cgm_getGameResultString().c_str());
      return; // nothing else to draw this frame
    }
    if (gs_lastGameOver)
      return; // keep showing the game-over screen

    // ----------------------------------------------------------------
    // 4. Detect piece lift (piece picked up, not yet placed)
    // ----------------------------------------------------------------
    char liftSq[3] = {0};
    bool liftDetected = cgm_getPieceLiftSquare(liftSq);
    if (liftDetected && (liftSq[0] != gs_liftSquare[0] ||
                         liftSq[1] != gs_liftSquare[1]))
    {
      gs_liftSquare[0] = liftSq[0];
      gs_liftSquare[1] = liftSq[1];
      gs_liftSquare[2] = 0;
      gs_liftShown = false; // force redraw of overlay
    }

    // ----------------------------------------------------------------
    // 5. Redraw full board when committed FEN changes
    // ----------------------------------------------------------------
    const String &committedFEN = cgm_getCommittedFEN();
    const String &incomingFEN = cgm_getIncomingFEN();
    const String &pendingFEN = cgm_getPendingFEN();
    bool isConfirming = cgm_isConfirming();
    bool inCheck = cgm_isInCheck();

    bool boardChanged = (committedFEN != gs_lastRenderedFEN);
    bool incomingChanged = (incomingFEN != gs_lastIncomingFEN);
    bool pendingChanged = (pendingFEN != gs_lastPendingFEN);

    if (boardChanged || incomingChanged || pendingChanged)
    {
      gs_lastRenderedFEN = committedFEN;
      gs_lastIncomingFEN = incomingFEN;
      gs_lastPendingFEN = pendingFEN;
      gs_lastConfirmState = false;
      // If the check alert banner was showing, restore the top label strip now
      // before the board redraw — drawGameScreen caches chrome and won't touch it.
      if (gs_lastCheckState)
      {
        clearCheckAlert();
        gs_timerDirty = true;
      }
      gs_lastCheckState = false;
      gs_liftShown = false;
      gs_lastTurnStatus = "";   // force status bar refresh after redraw
      gs_lastPanelCount = -2;   // board redraw wipes right panel — force chat repaint
      gs_timerDirty = true;     // board redraw wipes chrome — force timer repaint
      gs_lastHintBtnDrawn = -1; // chrome repaint clears hint slot — force redraw

      bool localWhite = cgm_isLocalPlayerWhite();
      // Show move highlight if we have a before/after pair
      if (incomingFEN.length() > 0)
      {
        // Remote move being applied — highlight on screen
        drawGameScreenWithMove(wifiNow, committedFEN, incomingFEN, localWhite, isAiGame);
      }
      else if (pendingFEN.length() > 0 && committedFEN.length() > 0)
      {
        // Local move validated, awaiting confirmation
        drawGameScreenWithMove(wifiNow, committedFEN, pendingFEN, localWhite, isAiGame);
      }
      else
      {
        bool fenValid = committedFEN.length() > 0;
        drawGameScreen(wifiNow, fenValid,
                       fenValid ? committedFEN : String("Waiting for game..."), localWhite, isAiGame);
      }
    }

    // ----------------------------------------------------------------
    // 5b. Refresh turn status in the status bar whenever it changes
    // ----------------------------------------------------------------
    if (!isConfirming && !cgm_isGameOver() && !cgm_isBoardSyncing())
    {
      const String &turnStatus = cgm_getTurnStatusString();
      if (turnStatus.length() > 0 && turnStatus != gs_lastTurnStatus)
      {
        gs_lastTurnStatus = turnStatus;
        displayStatusBar(turnStatus.c_str(), COLOR_RGB565_BLUE);
      }
    }

    // ----------------------------------------------------------------
    // 5c. Hint button — redrawn after chrome refresh or count change
    // ----------------------------------------------------------------
    if (!gs_messageComposeActive && !cgm_isChoosingPromotion() && !gs_lastGameOver &&
        gs_hintsLeft != gs_lastHintBtnDrawn)
    {
      gs_lastHintBtnDrawn = gs_hintsLeft;
      drawHintButton(gs_hintsLeft);
    }

    // ----------------------------------------------------------------
    // 6. Piece-lift overlay (drawn on top of the board without full redraw)
    // ----------------------------------------------------------------
    if (liftDetected && !gs_liftShown)
    {
      gs_liftShown = true;
      drawPiecePickedUp(gs_liftSquare);
    }
    else if (!liftDetected && gs_liftShown)
    {
      // Piece was placed — erase just the lift banner strip (no board repaint).
      gs_liftShown = false;
      gs_liftSquare[0] = 0;
      clearPieceLiftOverlay();
    }

    // ----------------------------------------------------------------
    // 7. Check alert banner (drawn on top of board)
    // ----------------------------------------------------------------
    if (inCheck && !gs_lastCheckState)
    {
      gs_lastCheckState = true;
      drawCheckAlert(cgm_isWhiteToMove()); // the side to move is in check
    }
    else if (!inCheck && gs_lastCheckState)
    {
      // Check resolved — erase just the check-alert strip (no board repaint).
      gs_lastCheckState = false;
      clearCheckAlert();
      gs_timerDirty = true; // clearCheckAlert repaints the opponent label strip
    }

    // ----------------------------------------------------------------
    // 8. Confirm / Cancel overlay
    // ----------------------------------------------------------------
    if (isConfirming && !gs_lastConfirmState)
    {
      gs_lastConfirmState = true;
      drawConfirmOverlay();
    }
    else if (!isConfirming && gs_lastConfirmState)
    {
      // Confirm dismissed — erase just the button area (no board repaint).
      gs_lastConfirmState = false;
      clearConfirmOverlay();
      gs_timerDirty = true; // clearConfirmOverlay restored the player label strip
    }
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

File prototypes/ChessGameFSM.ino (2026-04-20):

#include <Arduino.h>
#include <WiFi.h>
#include <WiFiClientSecure.h>
#include <HTTPClient.h>
#include <ArduinoJson.h>

// ============================================================
// ChessGameFSM.ino
// This file does three main jobs:
// 1. Manages gameplay with a real finite state machine
// 2. Tracks turns and detects when the game ends
// 3. Sends / receives board FEN state through your API
// ============================================================

// -------------------------
// External functions from move_api(1).ino
// -------------------------
String validateMoveAndReturnFEN(const String& beforeFEN,
                                const String& afterFEN,
                                bool whiteToMove,
                                const bool castling[4],
                                char promotionPiece);

bool parseFENBoard(const String& fen, char board[8][8]);
bool isKingInCheck(char board[8][8], bool whiteKing);
bool hasAnyLegalMove(char board[8][8], bool whiteToMove, const bool castling[4]);

// ============================================================
// User configuration
// ============================================================
namespace CGMConfig {
  const char* WIFI_SSID = "YOUR_WIFI_NAME";
  const char* WIFI_PASS = "YOUR_WIFI_PASSWORD";

  // Use your real endpoint here.
  const char* API_URL = "https://j3zvk9adv0.execute-api.us-east-2.amazonaws.com/api/v1/games/1/moves";

  const uint32_t POLL_INTERVAL_MS = 2000;
  const uint32_t LOCAL_STABLE_TIME_MS = 600;
  const uint32_t WIFI_RETRY_INTERVAL_MS = 5000;
  const uint32_t STATUS_PRINT_INTERVAL_MS = 1500;

  const uint16_t GAME_ID = 1;
  const uint8_t BOARD_NUMBER = 1;

  // false = local board plays black and waits for white first
  // true  = local board plays white and moves first
  const bool LOCAL_IS_WHITE = true;

  // Default promotion if you do not yet have a UI prompt
  const char DEFAULT_PROMOTION = 'Q';
}

// ============================================================
// Hooks that other files can call into
// ============================================================
// Your sensor code should call cgm_setPhysicalBoardFEN(...) every
// time it reconstructs the full physical board state.
//
// Touchscreen code can call:
//   cgm_confirmPendingMove();
//   cgm_cancelPendingMove();
//   cgm_requestNewGame();
// ============================================================

static String cgm_physicalBoardFEN = "";
static volatile bool cgm_moveConfirmed = false;
static volatile bool cgm_moveCancelled = false;
static volatile bool cgm_newGameRequested = false;
static volatile char cgm_requestedPromotion = CGMConfig::DEFAULT_PROMOTION;

void cgm_setPhysicalBoardFEN(const String& fen) {
  cgm_physicalBoardFEN = fen;
}

void cgm_confirmPendingMove() {
  cgm_moveConfirmed = true;
}

void cgm_cancelPendingMove() {
  cgm_moveCancelled = true;
}

void cgm_requestNewGame() {
  cgm_newGameRequested = true;
}

void cgm_setPromotionPiece(char piece) {
  cgm_requestedPromotion = piece;
}

// ============================================================
// Small helpers
// ============================================================

String cgm_boardOnlyFen(const String& fen) {
  int space = fen.indexOf(' ');
  if (space == -1) {
    return fen;
  }
  return fen.substring(0, space);
}

String cgm_startFen() {
  return "rnbqkbnr/pppppppp/8/8/8/8/PPPPPPPP/RNBQKBNR";
}

bool cgm_sameBoardFen(const String& a, const String& b) {
  return cgm_boardOnlyFen(a) == cgm_boardOnlyFen(b);
}

bool cgm_wifiConnected() {
  return WiFi.status() == WL_CONNECTED;
}

void cgm_copyCastle(const bool src[4], bool dst[4]) {
  for (int i = 0; i < 4; i++) {
    dst[i] = src[i];
  }
}

void cgm_resetCastle(bool rights[4]) {
  rights[0] = true;
  rights[1] = true;
  rights[2] = true;
  rights[3] = true;
}

bool cgm_sameBoard(char a[8][8], char b[8][8]) {
  for (int r = 0; r < 8; r++) {
    for (int c = 0; c < 8; c++) {
      if (a[r][c] != b[r][c]) {
        return false;
      }
    }
  }
  return true;
}

// Recomputes castling rights by looking only at board state.
// This is intentionally conservative.
// Once a king or rook is missing from its original square, the right is gone.
void cgm_rebuildCastlingRightsFromBoard(const String& fen, bool rights[4]) {
  char board[8][8];
  if (!parseFENBoard(fen, board)) {
    rights[0] = false;
    rights[1] = false;
    rights[2] = false;
    rights[3] = false;
    return;
  }

  rights[0] = (board[7][4] == 'K' && board[7][7] == 'R');
  rights[1] = (board[7][4] == 'K' && board[7][0] == 'R');
  rights[2] = (board[0][4] == 'k' && board[0][7] == 'r');
  rights[3] = (board[0][4] == 'k' && board[0][0] == 'r');
}

String cgm_squareName(int row, int col) {
  char file = 'a' + col;
  char rank = '8' - row;
  String out = "";
  out += file;
  out += rank;
  return out;
}

// For LEDs or debug messages. Works for ordinary moves and castles.
bool cgm_findMoveSquares(const String& beforeFEN,
                         const String& afterFEN,
                         int& fromRow, int& fromCol,
                         int& toRow, int& toCol) {
  char before[8][8];
  char after[8][8];

  if (!parseFENBoard(beforeFEN, before) || !parseFENBoard(afterFEN, after)) {
    return false;
  }

  int sourceCount = 0;
  int destCount = 0;
  fromRow = -1;
  fromCol = -1;
  toRow = -1;
  toCol = -1;

  for (int r = 0; r < 8; r++) {
    for (int c = 0; c < 8; c++) {
      if (before[r][c] == after[r][c]) {
        continue;
      }

      if (before[r][c] != '.' && after[r][c] == '.') {
        sourceCount++;
        if (fromRow == -1) {
          fromRow = r;
          fromCol = c;
        }
      }

      if (after[r][c] != '.' && before[r][c] != after[r][c]) {
        destCount++;
        toRow = r;
        toCol = c;
      }
    }
  }

  if (sourceCount >= 1 && destCount >= 1) {
    return true;
  }

  return false;
}

// ============================================================
// UI and LED hooks
// Replace these bodies with your real display and LED calls.
// ============================================================

void cgm_uiMessage(const String& line1, const String& line2 = "") {
  Serial.print("[UI] ");
  Serial.print(line1);
  if (line2.length() > 0) {
    Serial.print(" | ");
    Serial.print(line2);
  }
  Serial.println();
}

void cgm_ledClear() {
  // Replace with your LED strip clear / show logic.
}

void cgm_ledShowMoveSquares(const String& beforeFEN, const String& afterFEN) {
  int fromRow, fromCol, toRow, toCol;
  if (cgm_findMoveSquares(beforeFEN, afterFEN, fromRow, fromCol, toRow, toCol)) {
    Serial.print("[LED] Highlight ");
    Serial.print(cgm_squareName(fromRow, fromCol));
    Serial.print(" -> ");
    Serial.println(cgm_squareName(toRow, toCol));
  } else {
    Serial.println("[LED] Could not infer move squares");
  }
}
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

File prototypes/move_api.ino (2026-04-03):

#include <Arduino.h>

// ----------------------------
// Basic piece helpers
// ----------------------------

// Returns true if p is a white piece
bool isWhitePiece(char p) {
  return p >= 'A' && p <= 'Z';
}

// Returns true if the square contains a piece
bool isPiece(char p) {
  return p != '.';
}

// Returns true if both pieces are the same color
bool sameColor(char a, char b) {
  if (!isPiece(a) || !isPiece(b)) 
    return false;
  return isWhitePiece(a) == isWhitePiece(b);
}

// Returns true if p is a valid promotion piece
bool isValidPromotionPiece(char p) {
  char t = tolower(p);
  return t == 'q' || t == 'r' || t == 'b' || t == 'n';
}

// Makes promotion piece match mover color
char normalizePromotionPiece(char promotionPiece, bool white) {
  char t = tolower(promotionPiece);
  if (white) 
    return (char)toupper(t);
  return t;
}

// Copies one board into another
void copyBoard(char src[8][8], char dst[8][8]) {
  for (int r = 0; r < 8; r++) {
    for (int c = 0; c < 8; c++) {
      dst[r][c] = src[r][c];
    }
  }
}

// ----------------------------
// FEN parsing
// ----------------------------

// Parses only the board portion of a FEN string into an 8x8 array
// Empty squares are stored as '.'
bool parseFENBoard(const String& fen, char board[8][8]) {
  String boardPart = fen;

  // If a full FEN is passed in, keep only the first field
  int space = fen.indexOf(' ');
  if (space != -1) {
    boardPart = fen.substring(0, space);
  }

  int r = 0;
  int c = 0;

  for (int i = 0; i < boardPart.length(); i++) {
    char ch = boardPart[i];

    if (ch == '/') {
      if (c != 8) 
        return false;

      r++;
      c = 0;

      if (r > 7) 
        return false;
    }
    else if (ch >= '1' && ch <= '8') {
      int emptyCount = ch - '0';
      for (int k = 0; k < emptyCount; k++) {
        if (r > 7 || c > 7) 
            return false;
        board[r][c++] = '.';
      }
    }
    else {
      if (r > 7 || c > 7) 
        return false;
      board[r][c++] = ch;
    }
  }

  return r == 7 && c == 8;
}

// ----------------------------
// Board validation helpers
// ----------------------------

// Returns true only if board has exactly one white king and one black king
bool boardHasExactlyOneKingEach(char board[8][8]) {
  int whiteKings = 0;
  int blackKings = 0;

  for (int r = 0; r < 8; r++) {
    for (int c = 0; c < 8; c++) {
      if (board[r][c] == 'K') whiteKings++;
      if (board[r][c] == 'k') blackKings++;
    }
  }

  return whiteKings == 1 && blackKings == 1;
}

// Finds the king of one side
bool findKing(char board[8][8], bool whiteKing, int& kingRow, int& kingCol) {
  char king = whiteKing ? 'K' : 'k';

  for (int r = 0; r < 8; r++) {
    for (int c = 0; c < 8; c++) {
      if (board[r][c] == king) {
        kingRow = r;
        kingCol = c;
        return true;
      }
    }
  }

  return false;
}

// Compares two boards for exact equality
bool sameBoard(char a[8][8], char b[8][8]) {
  for (int r = 0; r < 8; r++) {
    for (int c = 0; c < 8; c++) {
      if (a[r][c] != b[r][c]) return false;
    }
  }
  return true;
}

// ----------------------------
// Piece movement helpers
// ----------------------------

// Returns true if squares between start and end are empty
// for a horizontal or vertical move
bool clearStraight(char board[8][8], int r1, int c1, int r2, int c2) {
  if (r1 == r2) {
    int step = (c2 > c1) ? 1 : -1;
    for (int c = c1 + step; c != c2; c += step) {
      if (board[r1][c] != '.') return false;
    }
    return true;
  }

  if (c1 == c2) {
    int step = (r2 > r1) ? 1 : -1;
    for (int r = r1 + step; r != r2; r += step) {
      if (board[r][c1] != '.') return false;
    }
    return true;
  }

  return false;
}

// Returns true if squares between start and end are empty
// for a diagonal move
bool clearDiagonal(char board[8][8], int r1, int c1, int r2, int c2) {
  int dr = r2 - r1;
  int dc = c2 - c1;

  if (abs(dr) != abs(dc)) return false;

  int rStep = (dr > 0) ? 1 : -1;
  int cStep = (dc > 0) ? 1 : -1;

  int r = r1 + rStep;
  int c = c1 + cStep;

  while (r != r2) {
    if (board[r][c] != '.') return false;
    r += rStep;
    c += cStep;
  }

  return true;
}

// Checks whether a pawn move is legal
// This handles normal pawn movement and captures
// Promotion is checked separately
bool validPawnMove(char board[8][8], int r1, int c1, int r2, int c2, char piece) {
  bool white = isWhitePiece(piece);
  int forward = white ? -1 : 1;
  int startRow = white ? 6 : 1;

  int dr = r2 - r1;
  int dc = c2 - c1;
  char dest = board[r2][c2];

  // Forward one into empty square
  if (dc == 0 && dr == forward && dest == '.') {
    return true;
  }

  // Forward two from starting row
  if (dc == 0 &&
      r1 == startRow &&
      dr == 2 * forward &&
      dest == '.' &&
      board[r1 + forward][c1] == '.') {
    return true;
  }

  // Diagonal capture
  if (abs(dc) == 1 &&
      dr == forward &&
      dest != '.' &&
      isWhitePiece(dest) != white) {
    return true;
  }

  return false;
}

// Knight move check
bool validKnightMove(int r1, int c1, int r2, int c2) {
  int dr = abs(r2 - r1);
  int dc = abs(c2 - c1);
  return (dr == 2 && dc == 1) || (dr == 1 && dc == 2);
}

// King move check for ordinary king move
bool validKingMove(int r1, int c1, int r2, int c2) {
  int dr = abs(r2 - r1);
  int dc = abs(c2 - c1);
  return dr <= 1 && dc <= 1 && (dr != 0 || dc != 0);
}

// Applies a normal move to a board
void applyMove(char board[8][8], int r1, int c1, int r2, int c2) {
  board[r2][c2] = board[r1][c1];
  board[r1][c1] = '.';
}

// Applies a promotion move to a board
void applyPromotion(char board[8][8], int r1, int c1, int r2, int c2, char promotionPiece) {
  board[r2][c2] = promotionPiece;
  board[r1][c1] = '.';
}

// ----------------------------
// Attack / check helpers
// ----------------------------

// Returns true if a pawn on (r,c) attacks (targetRow,targetCol)
bool pawnAttacksSquare(char board[8][8], int r, int c, int targetRow, int targetCol) {
  char piece = board[r][c];
  bool white = isWhitePiece(piece);
  int forward = white ? -1 : 1;

  return targetRow == r + forward && abs(targetCol - c) == 1;
}
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

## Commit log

2026-02-03 added pcb files for board
    [ECE-445-Chess-Board.kicad_pcb, ECE-445-Chess-Board.kicad_sch]
2026-02-03 added hall sensors and started ADC schematic
    [ADC_Suite.kicad_sch, ECE-445-Chess-Board.kicad_sch, HE_Row.kicad_sch]
2026-02-03 added initial board size 12inx12in
    [ECE-445-Chess-Board.kicad_pcb]
2026-02-16 new schematic architecture
    [ADC_Suite.kicad_sch, ECE-445-Chess-Board.kicad_pcb, ECE-445-Chess-Board.kicad_sch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]
2026-02-16 cleaned folders
    [untitled.kicad_sch]
2026-02-18 PSU done
    [Hall_Effect_Acquisition.kicad_sch, Main_Board_PCB.kicad_sch]
2026-02-23 ESP setup done
    [Main_Board_PCB.kicad_sch]
2026-02-24 started placement
    [ADC_Group.kicad_sch, Hall_Effect_Acquisition.kicad_sch, Main_Board_PCB.kicad_pcb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]
2026-02-26 PCB done
    [Hall_Effect_Acquisition.kicad_sch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]
2026-03-02 BOM csv added
    [Hall_Effect_Acquisition.kicad_sch, Main_Board_PCB.csv]
2026-03-08 Refactor ADC handling and update LED control
2026-03-29 Add header file with pin definitions
2026-03-30 Add touchscreen display test code for Arduino
2026-03-31 tile board created
    [Tile_PCB-B_Cu.gbr, Tile_PCB-B_Mask.gbr, Tile_PCB-B_Paste.gbr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]
2026-04-03 Add API documentation for ESP32 Smart Chessboard
    Add comprehensive API documentation for the ESP32 Smart Chessboard, detailing base URL, game model, endpoints, FEN format, error responses, and client flow.
2026-04-03 Add ADCdriver.ino file for ADC functionality
2026-04-03 Add README for ESP32 Chessboard firmware
    This README provides an overview of the ESP32 Chessboard firmware, including its architecture, file structure, key functions, and future improvements.
2026-04-07 uh fixing stuff and addin stuff making it easier to interact wit the display WHICH SUCLS
    [ChessBoard.ino]
2026-04-10 Add full ADC test implementation with LED indicators
    This file contains a complete ADC test implementation using I2C communication and LED indicators for ADC channel readings.
2026-04-10 Update pin definitions and improve formatting
2026-04-10 Fix SCL_DAQ definition from 32 to 39
    [headers.h]
2026-04-23 added edge case testing menu. Removed wifi settings, added promotion logic
2026-04-27 Minor bug fixes and improvements to UI
    [ChessBoard.ino, headers.h]
2026-04-27 timer and ai gamemode fixes also visual bug with checks
    [ChessBoard.ino, api_connect.cpp, gameloop.cpp]
2026-05-03 added 3d files for pieces and baseplates
    [Bishop_Piece_V1.stl, Cap_support_V1.f3d, Cap_support_v1.stl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]
2026-05-06 Add project timeline and meeting notes to README
    Added detailed project timeline and meeting notes for the Networked Physical Chess Board project, documenting key milestones, decisions, and technical challenges faced throughout development.
2026-05-06 Add prototypes for touchscreen display, ADC testing, and chess move validation
    - Created README.md for project documentation.
    - Implemented TouchscreenDisplayTestCode.ino for touchscreen interaction with UI.
    - Added full_ADC_test for reading multiple ADC channels and visualizing data with NeoPixels.
    - Introduced move_api.ino for validating chess moves and handling game logic.
    - Developed sketch_testHall.ino for testing ADC functionality with LED feedback.
